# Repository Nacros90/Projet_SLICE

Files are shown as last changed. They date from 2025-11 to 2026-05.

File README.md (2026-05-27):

# Projet SLICE
**Sliding Contact Investigation for Carbon Pantograph Wear Evaluation**

## Description
Ce projet est développé dans le cadre de la 2ème année de Licence de Physique / Sciences de l'Ingénieur. 
Il porte sur l'étude, la simulation et la conception d'un banc expérimental modélisant le contact glissant entre une caténaire et le pantographe d'un train. L'objectif principal est le maintien d'une **vitesse tangentielle constante ($V_t$)** lors du balayage d'un pion sur un disque en rotation, posant un défi cinématique d'asservissement non linéaire ($\omega = \frac{V_t}{r}$).

Ce dépôt regroupe l'intégralité du travail d'ingénierie : la modélisation mathématique initiale, la simulation interactive, le code de contrôle embarqué du banc d'essai et la conception assistée par ordinateur (CAO) des pièces mécaniques.

## Architecture du dépôt

* **Code/** : Contient les simulations cinématiques en Python (modélisation mathématique avec `pygame`) et les programmes C++ Arduino.
* **Documentation/** : Manuels techniques, documentations des composants électroniques (Shield CNC, drivers) et rapports académiques.
* **CAO/** : Fichiers `.stl` (ex: `support_disque.stl`) prêts pour l'impression 3D.

## Matériel et Prérequis

### Composants de la maquette physique
Le banc d'essai s'appuie sur une architecture matérielle spécifique pour s'affranchir des limites de calcul à haute fréquence :
* **Microcontrôleur :** Arduino UNO R4 Minima (Processeur ARM Cortex-M4 32-bits, 48 MHz)
* **Contrôle Moteur :** Shield CNC V3 avec Drivers A4988
* **Actionneurs :** Moteurs pas-à-pas (Axe X pour le disque rotatif, Axe Y pour le balayage linéaire)
* **Configuration mécanique :** Les drivers A4988 doivent être configurés en **Microstepping 1/8** (pontage matériel sur les broches M0 et M1) pour assurer la fluidité du mouvement.

### Outils logiciels
* [Python 3.x](https://www.python.org/) avec la bibliothèque `pygame` (pour la simulation logicielle)
* [Arduino IDE 2.x](https://www.arduino.cc/en/software) (pour la compilation et le téléversement du code embarqué)
* Un logiciel de tranchage (UltiMaker Cura, PrusaSlicer...) pour exploiter les modèles 3D

## Installation et Utilisation

### Étape 1 : Cloner le dépôt
```bash
git clone [https://github.com/nacros90/projet_slice.git](https://github.com/nacros90/projet_slice.git)
cd projet_slice
```

### Étape 2 : Lancer la Simulation (Python)
La simulation permet de visualiser la courbe de vitesse requise par rapport à la position du pion sans nécessiter le déploiement du matériel physique.
```bash
# Installation de la dépendance
pip install pygame

# Lancement du script principal
python Code/Python/slice.py
```

### Étape 3 : Déployer le Contrôle Matériel (Arduino)
Le programme embarqué opère en boucle ouverte et recalcule la vitesse du disque via un échantillonnage spatial régulier.

#### 3.1 Préparation matérielle
1. Ouvrez le fichier `Code/Arduino/Code_maquette_UNO_R4_MINIMA/Code_maquette_UNO_R4_MINIMA.ino` dans l'Arduino IDE.
2. Assurez-vous d'avoir installé le gestionnaire de carte **Arduino UNO R4 Boards**.
3. **Important :** Effectuez le "Zéro Mécanique" en plaçant manuellement le pion sur le bord extérieur du disque ($R_{max} = 7.5$ cm) avant toute mise sous tension.

#### 3.2 Configuration Système et Ports de communication
Avant de téléverser, configurez l'accès aux ports série selon votre système d'exploitation.

**Sous Microsoft Windows :**
* Branchez la carte et ouvrez le **Gestionnaire de périphériques** (`Win + X`).
* Déroulez l'onglet **Ports (COM et LPT)** pour identifier le port attribué (ex: `COM6`).
* *Note :* L'UNO R4 est reconnue nativement. Si vous utilisez une ancienne Nano, le pilote **CH340** peut être requis.
* Dans l'IDE Arduino, sélectionnez ce port COM.

**Sous GNU/Linux (Gestion des droits POSIX) :**
Par défaut, Linux restreint l'accès aux ports série (`/dev/ttyACM0` ou `/dev/ttyUSB0`), ce qui provoquera une erreur `Permission denied` lors du téléversement ou de l'exécution du code Arduino.
* Pour octroyer les droits de manière permanente, ajoutez votre utilisateur au groupe propriétaire du périphérique série :
  * Sous Debian / Ubuntu / Mint : `sudo usermod -aG dialout $USER`
  * Sous Arch Linux / Fedora : `sudo usermod -aG uucp $USER`
* Appliquez la modification sans redémarrer la session en tapant : `newgrp dialout` (ou `newgrp uucp`).
* Dans l'IDE Arduino, sélectionnez le port `/dev/tty...` correspondant.

#### 3.3 Téléversement et Diagnostic
* Cliquez sur **Téléverser** dans l'IDE. Une fois terminé, alimentez le Shield en puissance (8V).

*Matrice de résolution des problèmes courants :*
| Symptôme observé | Cause probable | Action corrective |
| :--- | :--- | :--- |
| **`Permission denied` (Linux)** | Droits restreints sur le port série. | Exécuter la commande `usermod` et `newgrp` (voir 3.2). |
| **Port COM invisible (Windows)** | Absence du pilote USB-Série. | Télécharger et installer le pilote CH340. |
| **`not in sync: resp=0x00`** | Parasitage matériel ou port occupé. | Débrancher le Shield CNC de l'Arduino pour le téléversement ou fermer les logiciels de tranchage 3D. |
| **Décrochage en fin de course** | Limite physique atteinte (FCEM sous 8V). | Vérifier que l'écrêtage à 10 000 pas/s (`constrain`) est bien actif dans le code. |

## Équipe Projet
* Naël CROSNIER
* Théliau FOULER
* Paul MITTLER
* Nysteroye Christ ZEBAZE NGUENA

*Supervisé par l'Université Marie et Louis Pasteur – UFR STGI Belfort*

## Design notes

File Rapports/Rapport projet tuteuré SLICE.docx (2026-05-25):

PROJET TUTEURÉ : SLICE

SLIDING CONTACT INVESTIGATION FOR CARBON PANTOGRAPH WEAR EVALUATION

Naël CROSNIER

Théliau FOULER

Paul MITTLER

Nysteroye Christ ZEBAZE NGUENA

Université Marie et Louis Pasteur – UFR STGI Belfort

Remerciements :

Nous tenons tout d’abord à remercier notre tuteur pédagogique pour ce projet, Philippe BAUCOUR pour son accompagnement tout au long de l’année, ses idées ainsi que ses précieux conseils ayant contribué à l’amélioration de notre maquette.

Nous souhaitons également remercier Cyrille VERNA pour sa disponibilité, son regard avisé sur l’ingénierie de la maquette, ses connaissances physiques et son implication sur l’impression 3D des pièces.

Nous exprimons notre plus grande gratitude envers Oreen OUMER pour le temps qu’il nous a consacré afin de nous présenter son banc d’essai et ses recherches ainsi que pour avoir répondu à nos nombreuses questions sur un sujet complexe.

Les cours de recherche documentaire donnés par Véronique NEYER et Caroline KIMMICH nous ont grandement aidés pour la recherche de sources en lien avec notre sujet, ainsi que dans la construction et la rédaction d’une bibliographie.

Enfin, nous adressons un dernier remerciement à Théo KZYAZIK qui, grâce à sa thèse, nous a permis de compléter notre travail avec des éléments scientifiques pertinents et approfondis.

## TABLE DES MATIERES

Présentation du sujet ............................................................................... p.

I. Etude théorique ................................................................................... p.

II. Amélioration de la maquette ................................................................ p.

2.1. Elements physiques .................................................................... p.

2.2. Arduino ........................................................................................ p.

III. Programmes et gestion des moteurs .................................................. p.

3.1. Arduino ........................................................................................ p.

3.2. Python .................................................... p.

IV. Résultats et Conclusion …………………........…………...................... p.

V. Références bibliographiques ............................................................... p.

VI. Annexes .............................................................................................. p.

6.1. Programme Arduino …………………………................................ p.

6.2. Programme Python ..................................................................... p.

## TABLE DES FIGURES

Figure 1 : Schéma de la liaison Caténaire-Pantographe ....................................... p.

Figure 2 : Photo de la maquette vue du dessus

Figure 3 : Schéma du “zig-zag” de la caténaire entre les poteaux ..................................... p.

Figure 4 : Représentation des grandeurs cinématiques d'un point en mouvement circulaire

Figure 5 : Photo de la maquette montrant le placement et les pièces entraînées par la courroie

## Présentation du sujet :

Les trains font partie des moyens de transport les plus fréquentés en France (environ 11% de la distance totale parcourue par des voyageurs en France en 2023 d’après touteleurope.eu), notamment dû à ses nombreux avantages comme sa sûreté, sa praticité ou bien son faible impact écologique. A l’heure actuelle, de nombreuses questions se posent à propos des trains, que ce que cela soit au niveau sécurité, prix ou encore énergétique. C’est de ce dernier aspect que nous allons plus particulièrement parler.

En effet, aujourd’hui, les trains utilisent un système nommé caténaire-pantographe pour s’alimenter en énergie (ici ce sera de l’énergie électrique).

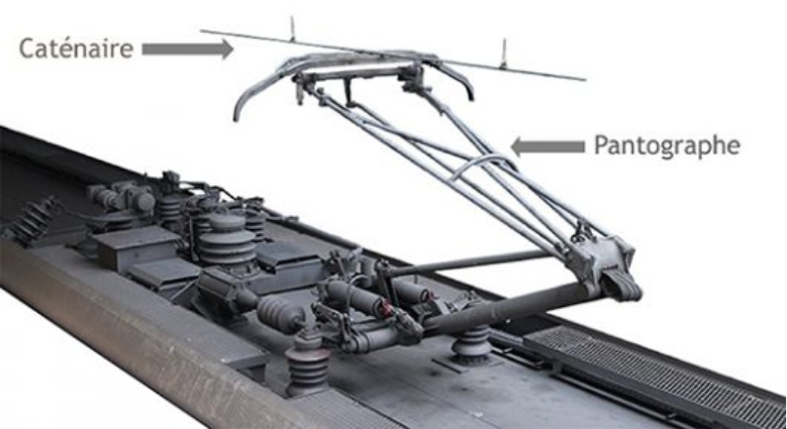
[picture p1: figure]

Figure 1 : Schéma de la liaison Caténaire-Pantographe.

Ce système est constitué d’une caténaire qui est un ensemble de câbles porteurs servant à acheminer l’électricité jusqu’au train. Cette dernière est transmise au train par le pantographe qui est un dispositif articulé formé d’une suite de bras ainsi que d’un archet sur lequel est fixée une bande de frottement. C’est ici que l’électricité va se transmettre au train.

C’est le contact entre caténaire et pantographe qui permet l’alimentation du train. Cette technologie permet un encombrement moindre par rapport aux anciennes technologies comme les locomotives à charbon et à vapeur mais possède un inconvénient de taille : le frottement. En effet, le frottement entre la bande du pantographe avec la caténaire use rapidement la bande sous l’action de la vitesse (plus ou moins grande suivant le type de train) ou encore la présence d’électricité. Cette usure, principalement sur la bande, est l’élément qui a poussé la SNCF en association avec FEMTO ST à travailler sur cette technologie en étudiant comment réduire cette usure et permettre une maintenance moins soutenue.

Pour bien comprendre la situation, nous avons commencé par récupérer la maquette conçue par le groupe affecté à ce même projet l’année dernière sous la tutelle de Philippe Baucour. Cette maquette est constituée d’un disque tournant ainsi que d’un pion (ici représenté par un crayon) dont on contrôlera la rotation ainsi que les déplacements grâce à l'utilisation de moteurs pas à pas et d’un microcontrôleur. Vous trouverez une photo de cette maquette ci-dessous.

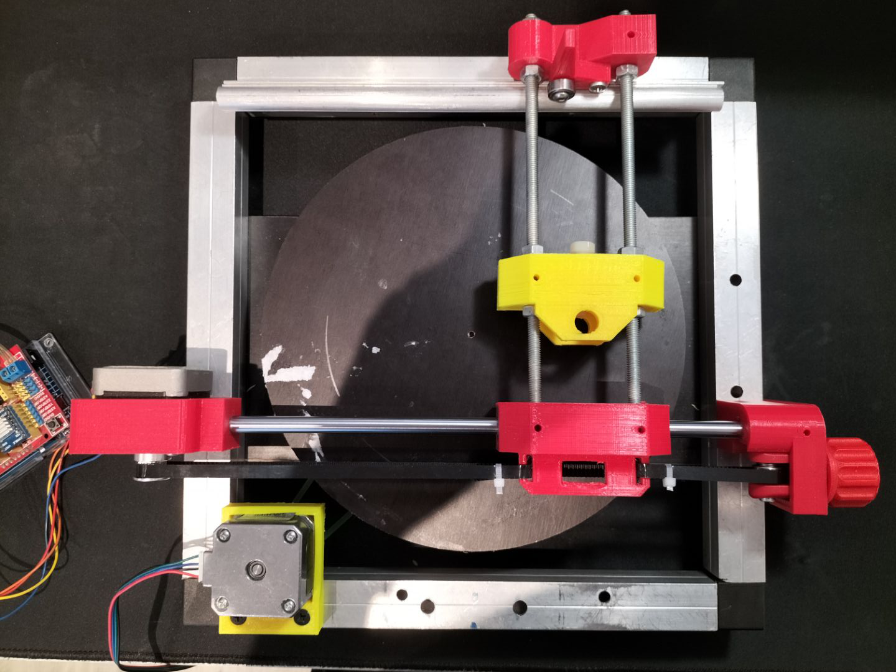
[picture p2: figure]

Figure 2 : Photo de la maquette vue du dessus

Cette maquette est directement inspirée du banc expérimental se trouvant à FEMTO ST

Nous avons justement pu voir ce banc en action et recevoir des explications concrètes sur son fonctionnement lors d’essai effectué par le thésard en charge du projet Oreen OUMER.

Le principe de ce banc est de représenter la vitesse du train (que l’on veut idéalement garder constante) par une vitesse de rotation (celle du disque précédemment cité) pour simuler l’avancement du train. Ce dernier sera quant à lui réduit au point de contact entre le caténaire et le pantographe représenté par un pion en carbone qui va venir se frotter sur le disque lorsque ce dernier tournera. Ce point de contact est déplaçable où l’on veut le long du rayon du disque grâce à des moteurs. Le déplacement le long du rayon sert quant à lui à prendre en compte le mouvement du point de contact entre le caténaire et le pantographe qui glisse le long de la bande de contact.

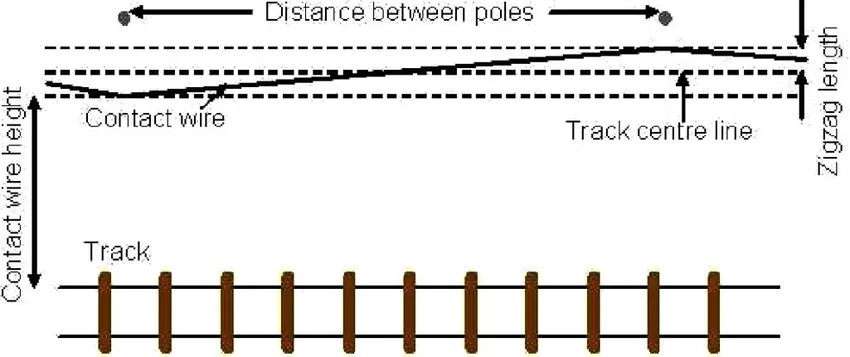
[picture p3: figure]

Figure 3 : Schéma du “zig-zag” de la caténaire entre les poteaux.

Ce mouvement du point est pensé pour réduire l’usure de la bande. En faisant varier la position du point de contact, la bande s’use sur toute sa longueur plutôt que sur un seul point ce qui permet d’augmenter sa durée de vie et de réduire ses risques de sciage.

Une fois cette maquette récupérée, nous avons donc pu commencer l’amélioration de cette dernière que cela soit au niveau de la maquette en elle-même (pièce, dimension, etc) mais surtout sur un autre aspect très important de ce projet qui est le contrôle des moteurs. Pour reproduire au mieux la réalité, la gestion des moteurs est cruciale. Ces moteurs sont contrôlés par un microcontrôleur géré en langage Arduino. Ce dernier nous permet de contrôler les moteurs à notre guise en changeant par exemple leur nombre de pas par seconde, donc leurs vitesses de rotation. La bonne gestion de ces moteurs passe aussi par une étude théorique des mouvements et vitesses des différents éléments de la maquette. Avec ces résultats, nous pouvons, une fois les avoir implantés dans le code Arduino, gérer le plus fidèlement possible à la réalité les moteurs.

Ce projet, étant destiné à être présenté au festival INOUIH, il doit pouvoir être compréhensible par le plus grand nombre. Cela nous amène donc à réfléchir sur comment vulgariser ce projet, les thèmes abordés et le fonctionnement de la maquette. Pour cela, en plus d’explications orales pour expliquer les principes fondamentaux, nous avons aussi cherché un moyen de montrer nos résultats et de les représenter de manière ludique et la plus compréhensible possible. Pour cela, nous utiliserons un programme python relié à un écran nous permettant de montrer l’influence des différents paramètres sur les résultats. Cette simulation se devra d’être le plus fidèle possible à la réalité, c’est pourquoi il faudra aussi y implémenter les différentes équations obtenues après l'étude théorique.

Comme nous avons pu le voir, ce projet possède plusieurs aspects très différents nécessaires au bon déroulement de ce dernier. Nous avons donc sectionné notre travail pour voir dans quel ordre les différentes tâches doivent être réalisées.

## I) Etude théorique :

La première étape de notre travail a été l'étude théorique du fonctionnement mécanique de la maquette. L’objectif étant d’en tirer des équations permettant le bon fonctionnement des programmes de gestion des moteurs. C’est donc une étape très importante. Pour commencer cela, nous partons d’une équation basique très souvent utilisée lors de problème avec des objets en rotation :

V_(tan) =ω⋅r

D’après cette équation, on a :

- V_(tan) (en m/s, qui est la vitesse tangentielle du train donc l’équivalent de sa vitesse réelle, censée être constante idéalement)
- ω (En rad/s) qui est la vitesse de rotation du disque
- r (en mm) étant le rayon du cercle définit par le point de contact entre le disque et le pion

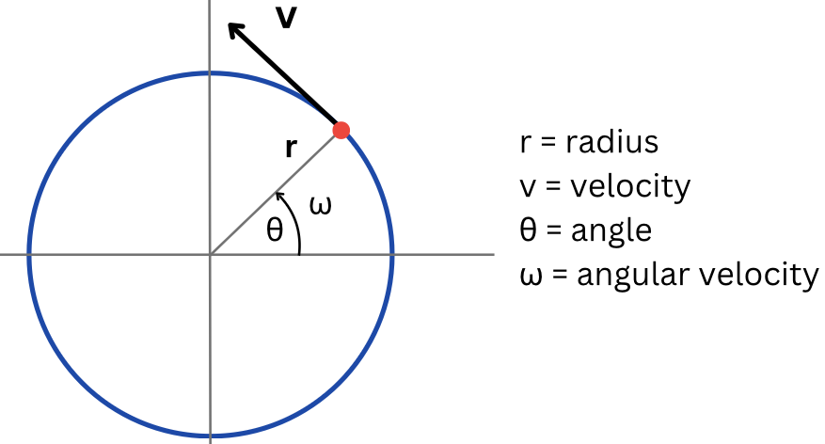
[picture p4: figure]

Figure 4 : Représentation des grandeurs cinématiques d'un point en mouvement circulaire.

Cette équation met donc en relation directe la vitesse tangentielle du train et la vitesse de rotation du disque ce qui nous permet de relier nos deux moteurs.

Notre base étant établie, nous allons maintenant utiliser cette équation pour l’adapter à notre situation. Comme nous le savons, nous avons 2 moteurs sur la maquette, chacun entraînant un élément différent et nécessitant donc une étude différente. Nous nommerons le moteur m_1 (moteur au support jaune) celui qui gère la rotation du disque et le moteur m_2 moteur au support rouge) celui qui gère le déplacement du pion sur le disque.

Pour mieux comprendre ce dont on parle, voici ci-dessous une photo de la maquette avec les différents éléments de cette dernière nommés :

L’objectif ici est de recalculer la vitesse tangentielle en direct pour s’assurer qu’elle reste constante. Les programmes seront chargés de calculer ω en fonction de r car le calcul de r quant à lui dépendra d’une autre relation qui est : d_p = (N⋅R_p)/360

Où N est le nombre de pas effectué par le moteur, Rp est le rayon de la poulie permettant le mouvement du pion le long du rayon du disque ( Rp = 70 mm )

Ce d_p est quant à lui la distance parcourue par le pion le long du rayon du disque. Cette distance sera ajoutée à notre ancien rayon r pour pouvoir le recalculer. Avec cette définition de r, cela nous permet de calculer ω en fonction d’un rayon calculable facilement et d’une vitesse tangentielle constante. Le nombre de pas se détermine expérimentalement pour que la gestion des moteurs soit la plus fluide possible mais tout cela se fera avec les différents programmes informatiques.

Grâce à l’aide de Monsieur Verna nous pu obtenir l’équation suivante :

V_(tan) =ω_1 ⋅r_1 =ω_2 ⋅r_2

Ici ω_1 et ω_2 sont les vitesses de rotation du disque à différents rayons r_1 et r_2 .

Avec ces différentes informations et équations, nous pouvons donc calculer ω en fonction de r qui lui est connu. Cela nous permet que, lorsque l’on fera varier le nombre de pas, ω varie lui aussi pour garder la vitesse tangentielle constante.

## II) Amélioration de la maquette :

### i. Eléments physiques

Une fois la maquette obtenue, nous avons commencé par tenter de là faire fonctionner pour voir s'il y avait d’éventuels problèmes. En effet, une fois la maquette active, des problèmes nous sont apparus comme principalement le fait que le disque n’est pas stable une fois qu’il est en rotation ou encore qu’il tourne de manière saccadée et peu précise. Nous avons donc compris que des améliorations de la maquette s’imposait. C’est ce dont on va parler dans cette partie.

Pour commencer, nous avons cherché à régler le problème de stabilité du plateau. Pour cela, nous avons vu avec M. VERNA et M. BAUCOUR pour modéliser une pièce 3D afin de mieux y fixer le plateau et ainsi éviter tout oscillement. Une première idée était d’entourer le moyeu central et de former une sorte de plateau pour y fixer le disque mais finalement l’essai s’est avéré non concluant. Une seconde idée était une pièce se mettant autour du moyeu mais s’insérant dans le plateau afin d’y mettre une vis et un une vis oreille afin de pouvoir démonter le plateau de façon rapide et simple. Après prise de mesure, modélisation 3D sur Onshape, un premier essai non fonctionnel à cause d'erreurs de mesures, nous avons enfin eu la pièce finale réglant parfaitement le problème.

### ii. Arduino

Le second point d’amélioration est la partie programmation dans le langage Arduino, nous asservissons les moteurs par le biais d’une carte Arduino, dans là qu’elle nous téléversons du code. L’un des objectifs majeurs de cette parties était de programmer un script qui était conforme aux équations mécaniques et cinématiques régissant les mouvements du système plateau-pion.

Initialement confié à une carte Arduino Nano (équipée d'un microcontrôleur ATmega328P), le système souffrait d'un goulot d'étranglement calculatoire sévère. Le maintien de la consigne avec notre rapport de transmission exigeait la génération d'environ 13 300 impulsions par seconde. L'architecture 8-bits de la Nano, cadencée à 16 MHz et dépourvue d'unité de calcul en virgule flottante (FPU), devait émuler les opérations non linéaires complexes de la boucle d'asservissement (divisions, variables de type float, calculs impliquant pi) de manière purement logicielle. Cela entraînait une saturation de l'horloge processeur autour de 4 000 pas/s et un figeage cinématique de la maquette.

La migration vers une carte Arduino UNO R4 Minima a permis de lever cette limite matérielle. Embarquant un processeur ARM Cortex-M4 (32-bits) cadencé à 48 MHz, cette carte intègre une FPU matérielle. Cette architecture permet d'exécuter les opérations en virgule flottante en un nombre très réduit de cycles d'horloge. La boucle logicielle peut désormais générer des fréquences dépassant les 20 000 pas/s sans induire de latence.

L'interface de puissance entre la logique 5V du microcontrôleur et l'alimentation 8V des moteurs pas-à-pas est assurée par un Shield CNC V3 équipé de drivers de type A4988.

Un moteur pas-à-pas standard effectue 200 pas entiers par tour (soit une résolution angulaire de 1,8° par pas). En mode "Full Step", chaque transition de phase génère des transitoires de couple et des résonances mécaniques nuisibles à l'étude tribologique du contact glissant, qui requiert une continuité parfaite.

Afin de lisser la dynamique du mouvement, nous avons modifié la configuration matérielle de la carte de commande pour forcer un fonctionnement en Microstepping.

Tableau : Configuration des états logiques du driver A4988 (Microstepping 1/8)

Paires de broches | État Logique cible | Action matérielle réalisée
M0 (ou MS1) | HIGH (1) | Pont de court-circuit effectué (soudage)
M1 (ou MS2) | HIGH (1) | Pont de court-circuit effectué (soudage)
M2 (ou MS3) | LOW (0) | Contact laissé ouvert

Cette subdivision électronique des courants de phase régule l'intensité sous forme de signaux pseudo-sinusoïdaux, portant la résolution à 1 600 micro-pas par tour. Le mouvement linéaire du pion est ainsi devenu strictement continu, limitant l'excitation des modes propres de la structure.

L'affranchissement des limites logicielles de traitement a mis en exergue une contrainte purement électromagnétique de l'actionneur. Lors du passage du pion dans la zone centrale du disque, la consigne haute fréquence du microcontrôleur provoquait une perte de synchronisme et un décrochage brutal du moteur du plateau (phénomène observé autour de 11 000 pas/s, soit environ 412 Tr/min).

Ce comportement est gouverné par la Force Contre-Électromotrice (FCEM) et l'inductance (L) des enroulements du moteur. La dynamique de montée du courant dans la bobine est régie par l'équation de maille temporelle : (di)/(dt)=(U−E)/L (où E est la FCEM induite par la rotation du rotor).

À haute vitesse angulaire, l'inversion rapide du champ et la forte valeur de la FCEM s'opposent à l'établissement du courant. Sous notre tension d'alimentation contrainte à 8V, le gradient de courant (di)/(dt) est d'autant plus limité : le courant n'a physiquement plus le temps d'atteindre sa valeur nominale avant la commutation de phase suivante. Le couple moteur s'effondre drastiquement, ne parvenant plus à vaincre l'inertie du disque.

Pour pallier cette limitation physique directement imputable à l'alimentation de 8V, un écrêtage par saturation logicielle (limite fixée à 10 000 pas/s) a été implémenté. Ce compromis garantit la stabilité électromagnétique du système en boucle ouverte en bornant le fonctionnement à un domaine cinématique viable.

Un élément important de la maquette est la courroie. Elle sert à transmettre le mouvement créer par le moteur m_1 à l’axe sur lequel le disque se fixe pour pouvoir tourner.

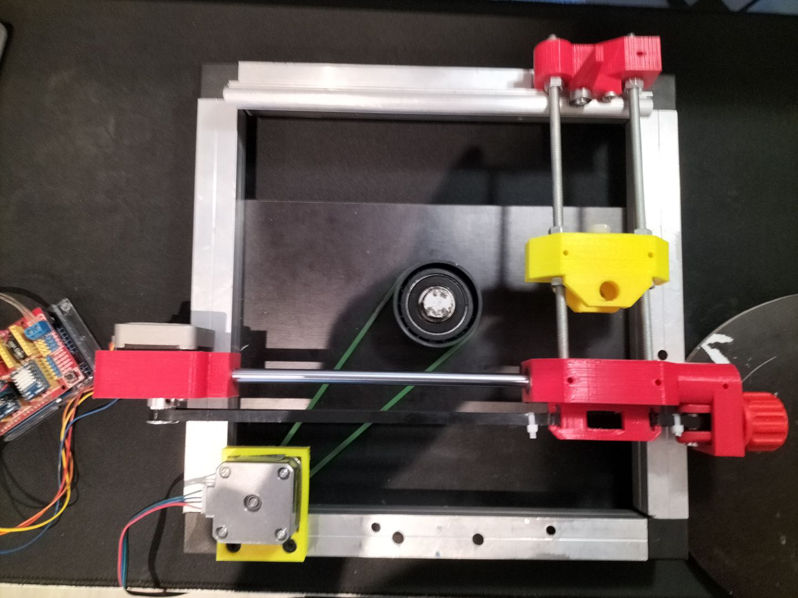
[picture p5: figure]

Figure 5 : Photo de la maquette montrant le placement et les pièces entraînées par la courroie

Cette dernière n’était plus assez tendue donc Monsieur Verna nous en a refait une avec les mêmes dimensions pour nous assurer une plus grande fiabilité et une meilleure précision.

Cette maquette doit permettre de visualiser nos résultats c’est pourquoi nous avons décidé de réfléchir à comment améliorer cette visualisation. Nous avons donc décidé de changer le support servant à représenter le point de contact entre le pion et le disque. Avant, ce pion était modélisé par un crayon que l’on pose sur un support pour que la trajectoire du pion se dessine sur une feuille de papier collée sur le disque quand ce dernier tourne. Cela posait des problèmes de frottements car pour avoir un trait visible, il fallait appuyer le crayon assez fort ce qui n’était pas pratique. De plus, le mouvement saccadé du disque dû aux problèmes précédemment cités, entrainait une trajectoire dessinée peu précise. Pour changer cela, le précédent groupe avait donc penser à utiliser un revêtement de type tableau blanc à coller sur le disque pour que le crayon remplacé par un feutre, puisse plus simplement dessiner la trajectoire du pion en réduisant l’influence des frottements sur les résultats obtenus. Nous avons donc repris cette idée car cela permet aussi de pouvoir effacer la trajectoire dessinée plus facilement qu’avec du papier classique.

D’autres problèmes plus légers sont aussi à régler comme :

- la fixation des moteurs sur leur support, notamment le moteur m_2 qui lorsque la maquette est active, n’était pas très stable. Ce problème détecté par Monsieur Verna lors d’un entretien, a tout de suite été corrigé après avoir fixé ces moteurs aux supports avec des vis.

- la stabilisation générale de la maquette et la diminution des vibrations. Pour cela, nous avons placés des patins anti-dérapants que l’on a collé sous les pieds de la maquette pour réduire les vibrations qu’elle subissait quand elle était active.

Comme nous avons pu le voir, la structure et le fonctionnement général de la maquette n’a pas été modifié. Notre travail se situe surtout la stabilisation des éléments de la maquette comme le disque, la bonne transmission des informations et mouvements avec la gestion des équipements du micro-processeur et de la courroie ou encore améliorer la visibilité de nos résultats.

## III) Programmes et gestion de moteurs :

Pour pouvoir mener à bien nos tests et expériences, il nous faut utiliser des programmes informatiques pour pouvoir gérer les moteurs et afficher nos résultats afin de mieux comprendre ce qu’il se passe. Nous allons donc utiliser deux programmes différents : le premier est un code Arduino qui, à l’aide du microcontrôleur de la carte Arduino, nous permettras de contrôler les moteurs de la manière la plus précise voulue afin d’obtenir les meilleurs résultats possibles. Le deuxième est un programme Python qui sert quant à lui à afficher nos résultats de manière visuelle pour simplifier la compréhension du sujet à un public non initié.

Nous allons commencer par aborder le programme Arduino car il est nécessaire au bon fonctionnement de la maquette.

### iii. Arduino

Contrairement au code Python dont l'objectif principal est la simulation et la visualisation des données, le programme Arduino constitue le cœur opérationnel de notre maquette. Son rôle est de traduire les résultats de notre étude cinématique théorique en signaux électriques concrets afin de piloter les moteurs pas-à-pas en temps réel. Pour garantir une gestion précise des signaux, ce programme s'appuie sur la bibliothèque externe AccelStepper et a été rigoureusement structuré en trois blocs distincts.

1. Initialisation et Variables globales

Ce premier bloc prépare l'environnement matériel et logiciel de la carte (Arduino UNO R4 Minima). Il définit d'abord le câblage du microcontrôleur vers le Shield CNC, puis modélise les caractéristiques mécaniques de la maquette, notamment l'activation du Microstepping (réglé sur 1/8 de pas pour réduire les vibrations) et l'intégration de notre rapport de transmission (multiplicateur_mecanique). C'est également ici que sont déclarées les constantes physiques fondamentales au cœur de l'étude, à savoir la vitesse tangentielle cible (25 cm/s) et les limites spatiales du disque. Enfin, pour protéger l'intégrité du matériel, des garde-fous logiciels (écrêtage de la vitesse maximale) sont fixés afin d'éviter le décrochage électromagnétique du moteur face aux très hautes fréquences d'impulsion.

2. Boucle principale

Ce bloc, s'exécutant en continu à haute fréquence, constitue le cœur de notre asservissement. Il orchestre deux processus cinématiques simultanés. D'une part, il gère le balayage linéaire du pion en contrôlant ses allers-retours autonomes entre le bord et le centre du disque. D'autre part, il assure la régulation dynamique de la vitesse du plateau. Afin d'optimiser la puissance de calcul du processeur et d'éviter les saccades, le recalcul de la vitesse n'est pas effectué à chaque micro-pas, mais selon un échantillonnage spatial défini (SEUIL_PAS_Y). À chaque palier, le programme déduit le rayon actuel et applique l'équation cinématique de base ( ω=(V_(tan))/r ) pour ajuster instantanément la vitesse de rotation du disque. L'écrêtage de sécurité (constrain) garantit que si la vitesse angulaire requise tend vers l'infini près du centre du disque, elle est automatiquement bridée au plafond toléré par le moteur.

3. Fonctions mathématiques

Le dernier bloc regroupe les outils de conversion essentiels au système. L'architecture de la maquette fonctionnant en boucle ouverte (sans capteur de position absolu), l'Arduino est initialement aveugle à la position physique du pion. Ces fonctions permettent de lier les variables informatiques à la réalité mécanique. Elles convertissent les grandeurs mécaniques (RPM) en signaux électriques temporels (pas par seconde), et surtout, elles convertissent le comptage logiciel des pas du moteur en une véritable coordonnée spatiale géométrique (le rayon actuel en centimètres), donnée indispensable à la résolution de l'équation dans la boucle principale.

### iv. Python

Nous allons maintenant nous penchés sur le code Python. Ce dernier n’est pas nécessaire au fonctionnement de la maquette car il ne commande pas les moteurs. Son but est de visualiser les résultats de manière ludique et compréhensible. Pour cela, nous avons utilisé une bibliothèque appelée Pygame. C’est un ensemble de module nous permettant de créer des simulations comme celle utilisée ou bien même des jeux comme nous avons pu le faire lors d’un cours du premier semestre. Cette bibliothèque est très utile car elle nous permet de structurer le code de la simulation comme on le souhaite.

En effet, un code bien construit permet une exploration et utilisation plus simple de celui-ci. C’est pourquoi nous avons arrangé notre code en plusieurs blocs ayant tous une fonction propre.

Le premier bloc sert à initialiser donc définir toutes les variables dont on a besoin ainsi qu'importer toutes les bibliothèques nécessaires dont Pygame. Les autres bibliothèques servent quant à elles à nous permettre d’utiliser des fonctions mathématiques ou encore de faciliter la gestion des objets en mouvements. Ce bloc est la base du code, il est donc important de définir toutes les variables dont nous avons besoin pour plus tard. Ces variables peuvent être les différentes grandeurs physiques comme des vitesses ou des rayons ou bien encore des éléments de la simulation comme la taille de l’écran ou bien les couleurs de ce dernier.

Le deuxième bloc sert à définir les fonctions. Ces fonctions transforment et utilisent les variables définies avant pour effectuer des calculs comme ceux de la vitesse tangentielle, tracer des formes comme le pion que l’on va faire bouger. Ces fonctions forment la structure de la simulation. Ce sont elles qui vont définir son apparence, comment elle va traiter les données et à quoi elle va servir. Elles sont en quelques sortes le squelette de la simulation. Il est donc logique de les séparer de l’initialisation des variables (qui est naturellement avant les fonctions) et de la suite du code qui sert encore à une autre chose.

Le dernier bloc est celui de la boucle principale. Cette boucle est le cœur du programme. Elle commence dès que l’utilisateur lance le programme et s’arrête lorsque l’utilisateur le ferme. Elle sert à actualiser les données et à les afficher en temps réel. Elle gère la gestion des entrées donc les touches utilisées par l’utilisateur, met à jour les résultats des calculs et rafraichît l’affichage de la simulation à chaque fois que la boucle est effectuée. Cette boucle se servant des fonctions et des variables, il est logique de la placer à la toute fin de ce dernier pour lui permettre d’utiliser tout ce dont elle a besoin.

L’objectif de séparer le code en plusieurs blocs est double : trouver plus simplement les lignes et les parties que l’on veut et permettre une meilleure compréhension de la logique d’un code et du fonctionnement de la simulation.

## IV) Résultats et Conclusion :

En conclusion, les développements matériels et logiciels apportés à la maquette initiale ont permis de répondre pleinement aux exigences de ce banc d'essai cinématique. Comme l'a validé notre simulation Python en amont, l'implémentation de notre modèle mathématique garantit le maintien d'une vitesse tangentielle constante en dépit de la variation continue du rayon. Le défi majeur des saccades mécaniques a été résolu par l'exploitation du microstepping (1/8 de pas), apportant ainsi la fluidité de glissement indispensable à une modélisation de l'usure du pantographe.

Par ailleurs, l'optimisation de ce système ne s'est pas limitée à l'aspect algorithmique. La conception et l'impression 3D de nouvelles pièces de maintien, couplées à l'ajout de patins amortisseurs, ont considérablement réduit les résonances et stabilisé le disque en rotation.

D'un point de vue gestion de projet, ce travail a mis en lumière l'importance d'une planification rigoureuse. L'organisation initiale s'est révélée sous-optimale face à la complexité du travail prévue, entraînant des retards notables sur notre calendrier prévisionnel. Toutefois, cette confrontation à la réalité expérimentale nous a poussés à réévaluer nos méthodes de travail collaboratif. Cette capacité d'adaptation nous a permis de surmonter ces obstacles et d'atteindre, in fine, l'ensemble des objectifs techniques fixés.

Ce projet nous a ainsi permis de consolider une approche d'ingénierie multidisciplinaire, alliant la modélisation théorique, la programmation embarquée et la conception mécanique. La maquette est aujourd'hui fonctionnelle, stabilisée et fidèle à la réalité physique.

## V) Bibliographie :

[https://ecampusontario.pressbooks.pub/] (figure 3)

https://www.researchgate.net/figure/Layout-of-an-overhead-electrified-railway-showing-the-zigzag-of-the-contact-wire-adapted_fig3_224219101

https://actgv.fr/wp-content/uploads/2014/04/cat%C3%A9naire-et-fils-de-contact.pdf

- Enrici P, Martiré T, Coillot C, Huselstein JJ. Maquette analogique pour l’étude de boucle de régulation. Application à la régulation d’un Moteur à Courant Continu. Journal sur l'enseignement des sciences et technologies de l'information et des systèmes. 2023;22:1015.
- Janssoone D. Manuel d’exploitation ferroviaire: formation des exploitations du ferroviaire, IUT, CNAM, écoles d’ingénieurs. Malakoff: Dunod; 2024.
- Bausseron T. Etude de l'échauffement de la caténaire lors du captage à l'arrêt: développement d'un outil informatique [Thèse de doctorat]. Besançon: Université de Franche-Comté; 2014.
- Jonckheere B. Caractérisation multi-physique d'une interface multi-contacts à l'arrêt et en mouvement: cas du captage de courant via l'interface caténaire-pantographe [Thèse de doctorat en ligne]. Amiens: Université de Picardie Jules Verne; 2021 [cité 13 novembre 2025]. Disponible sur: https://theses.hal.science/tel-03828928
- Cincou A, Fortin C. Guide de modélisation 3D: document de référence. Montréal: Presses Internationales Polytechnique; 2019.
- Kziazyk T. Etude expérimentale de l'usure et de l'échauffement d'un contact électrique glissant: application caténaire-pantographe [Thèse de doctorat en ligne]. Besançon: Université de Bourgogne Franche-Comté; 2023 [cité 06 novembre 2025]. Disponible sur: https://ariane.umlp.fr/discovery/fulldisplay?docid=alma991006709719506657&contex t=L&vid=33UFC_INST:33UFC_INST&lang=fr&search_scope=MyInst_and_CI&adapt or=Local%20Search%20Engine&tab=Everything&query=any,contains,Etude%20exp %C3%A9rimentale%20de%20l%27usure%20et%20de%20l%27%C3%A9chauffeme nt%20d%27un%20contact%20%C3%A9lectrique%20glissant%20:%20application%2 0cat%C3%A9naire-pantographe&offset=0
- Delcey N. Modélisation électro-thermique d’un pantographe pour un train en mouvement [Thèse de doctorat en ligne]. Besançon: Université de Bourgogne Franche-comté; 2018 [cité 05/12/2025] Disponible sur : https://ariane.umlp.fr/discovery/fulldisplay?docid=alma991006234119706657&contex t=L&vid=33UFC_INST:33UFC_INST&lang=fr&search_scope=MyInst_and_CI&adapt or=Local%20Search%20Engine&tab=Everything&query=any,contains,contact%20ele ctrique%20pour%20les%20trains&offset=0
- Sreejyothi KR, Chenchireddy K, Srujana A, Nagaraju D, Ramcharan G, Raghu D. Arduino based stepper motor speed regulation for robotics applications. International Journal of Applied Power Engineering (IJAPE) [En ligne]. 2024 [cité 05 décembre 2025];13(3):695-702. Disponible sur: http://doi.org/10.11591/ijape.v13.i3.pp695-702

## VI) Annexe

### v. Code Arduino :

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
//Maquette de démonstration pour le projet SLICE

//Objectif : Contrôler un moteur linéaire (pion) et un moteur rotatif (disque) en synchronisation

//avec une vitesse tangentielle constante pour le pion.

//

//Matériel :

//- Arduino UNO R4 MINIMA

//- Shield CNC pour contrôler les moteurs pas à pas

//- Moteur linéaire (pion) avec driver compatible

//- Moteur rotatif (disque) avec driver compatible

//

//Fonctionnement :

//- Le moteur Y (pion) effectue un mouvement linéaire aller-retour entre deux positions définies.

//- Le moteur X (disque) ajuste sa vitesse de rotation en fonction de la position du pion pour maintenir une vitesse tangentielle constante.

//

//Note : Ce code est conçu pour être utilisé en mode FULL STEP pour une meilleure précision et un contrôle plus fin des moteurs. Assurez-vous que les drivers de vos moteurs sont configurés pour le microstepping approprié (1/8 dans ce cas) pour correspondre aux constantes définies dans le code.

// 1. --- Initialisation et Variables globales ---

#include <AccelStepper.h>

// --- BROCHES DU SHIELD CNC ---

#define EN 8 // Broche d'activation du shield

#define STEP_Y 3 // Broche STEP du moteur Y (pion)

#define DIR_Y 6 // Broche DIR du moteur Y

#define STEP_X 2 // Broche STEP du moteur X (plateau/disque)

#define DIR_X 5 // Broche DIR du moteur X

// --- RÉSOLUTION MÉCANIQUE (FULL STEP) ---

const int MICROSTEPPING = 8; // Microstepping du driver (1/8 de pas)

const float multiplicateur_mecanique = 2.83;

const int stepsPerRevolutionX = (200 * MICROSTEPPING) * multiplicateur_mecanique; // Pas par tour du moteur X

const int stepsPerRevolutionY = 200 * MICROSTEPPING; // Pas par tour du moteur Y

// --- CONSTANTES PHYSIQUES ---

const float VITESSE_TANGENTIELLE_CIBLE = 25.0; // Vitesse tangentielle du pion en cm/s

const float vitesseY_RPM = 0.5; // Vitesse de rotation du moteur Y en RPM

const int pasParCycle = 290 * MICROSTEPPING; // Nombre de pas pour un cycle aller-retour du pion

const float RAYON_MAX = 7.5; // Rayon maximal du disque en cm

const float RAYON_MIN = 1.35; // Rayon minimal du disque en cm

// --- CONSTANTES DE RÉGLAGE LOGICIEL ---

const long SEUIL_PAS_Y = 16; // Seuil de variation en pas pour recalculer la vitesse X

const float VITESSE_X_MIN = 10.0; // Vitesse minimale autorisée pour le plateau X

const float VITESSE_X_MAX = 10000.0; // Vitesse maximale autorisée pour le plateau X

const float SEUIL_DIFF_VITESSE_X = 2.0; // Seuil de variation de vitesse pour appliquer un nouveau réglage

AccelStepper moteurY(AccelStepper::DRIVER, STEP_Y, DIR_Y);

AccelStepper moteurX(AccelStepper::DRIVER, STEP_X, DIR_X);

long positionDepart = 0; // Position au début du cycle Y

long positionCible = pasParCycle; // Position cible initiale pour le mouvement Y

long dernierPasY = 0; // Position Y mémorisée pour limiter les recalculs

float vitesseX_actuelle = 0.0; // Vitesse courante appliquée au moteur X

void setup() {

Serial.begin(115200);

// --- ACTIVATION DU SHIELD ---

pinMode(EN, OUTPUT);

digitalWrite(EN, LOW);

// Initialisation Moteur Y (Pion)

moteurY.setMaxSpeed(convertRPMToStepsPerSec(vitesseY_RPM, stepsPerRevolutionY));

moteurY.setSpeed(convertRPMToStepsPerSec(vitesseY_RPM, stepsPerRevolutionY));

// Initialisation Moteur X (Disque)

moteurX.setMaxSpeed(VITESSE_X_MAX);

moteurX.setSpeed(100);

Serial.println("Initialisation SLICE (Mode FULL STEP) OK.");

}

// 2. --- BOUCLE PRINCIPALE ---

void loop() {

moteurY.runSpeed();

moteurX.runSpeed();

// --- GESTION DU MOTEUR Y (ALLER-RETOUR DU PION) ---

// Quand le pion atteint la cible, on inverse sa direction

if ((moteurY.currentPosition() >= positionCible && moteurY.speed() > 0) ||

(moteurY.currentPosition() <= positionCible && moteurY.speed() < 0)) {

moteurY.setSpeed(-moteurY.speed());

positionDepart = moteurY.currentPosition();

// Nouvelle cible dépendante du sens actuel du mouvement

positionCible = positionDepart + (pasParCycle * (moteurY.speed() > 0 ? 1 : -1));

Serial.print("Inversion Y. Cible : ");

Serial.println(positionCible);

}

// --- ASSERVISSEMENT DU MOTEUR X (VITESSE DU DISQUE) ---

long positionY = abs(moteurY.currentPosition());

if (abs(positionY - dernierPasY) >= SEUIL_PAS_Y) {

float rayon = mapPasToRayonSymetrique(positionY);

// Calcul de la vitesse angulaire nécessaire pour garder la vitesse tangentielle cible

float vitesseX = (VITESSE_TANGENTIELLE_CIBLE * stepsPerRevolutionX) / (2.0 * PI * rayon);

vitesseX = constrain(vitesseX, VITESSE_X_MIN, VITESSE_X_MAX);

if (abs(vitesseX - vitesseX_actuelle) > SEUIL_DIFF_VITESSE_X) {

moteurX.setSpeed(vitesseX);

vitesseX_actuelle = vitesseX;

Serial.print("Rayon(cm):");

Serial.print(rayon);

Serial.print("\tVitesse_Plateau(pas/s):");

Serial.print(vitesseX);

Serial.print("\tPosition_Pion(pas):");

Serial.println(positionY);

}

dernierPasY = positionY;

}

}

// --- FONCTIONS MATHÉMATIQUES ---

float convertRPMToStepsPerSec(float rpm, int stepsPerRev) {

return (rpm * stepsPerRev) / 60.0;

}

float mapPasToRayonSymetrique(long pas) {

long cycle = pas % (2 * pasParCycle);

float phase = (cycle < pasParCycle) ? (float)(pasParCycle - cycle) / pasParCycle

: (float)(cycle - pasParCycle) / pasParCycle;

return RAYON_MIN + (RAYON_MAX - RAYON_MIN) * phase;

}

### vi. Code Python:

import sys # Permet de quitter proprement le programme

import math # Permet d’utiliser pi, cos, sin, etc.

import pygame # Bibliothèque utilisée pour l’affichage graphique

pygame.init() # Initialisation de Pygame

# =========================================================

# FENÊTRE

# =========================================================

WIDTH, HEIGHT = 1400, 900 # Dimensions de la fenêtre

FPS = 60 # Nombre d’images par seconde

screen = pygame.display.set_mode((WIDTH, HEIGHT)) # Création de la fenêtre

pygame.display.set_caption("SLICE - Banc expérimental avec courbes") # Titre

clock = pygame.time.Clock() # Horloge pour contrôler la vitesse

# =========================================================

# COULEURS

# =========================================================

DARK_BG = (6, 8, 18) # Fond sombre

PANEL_BG = (235, 240, 250) # Fond clair des panneaux

WHITE = (245, 245, 245) # Blanc

BLACK = (0, 0, 0) # Noir

GRAY = (80, 90, 110) # Gris

YELLOW = (255, 220, 80) # Jaune

COPPER = (190, 115, 45) # Couleur cuivre du disque

COPPER_LIGHT = (230, 150, 70) # Cuivre clair

COPPER_DARK = (90, 50, 20) # Cuivre foncé

CARBON = (45, 45, 45) # Couleur du pion carbone

BLUE = (40, 120, 255) # Bleu

RED = (255, 80, 80) # Rouge

GREEN = (80, 200, 120) # Vert

# =========================================================

# POLICES

# =========================================================

FONT = pygame.font.SysFont("consolas", 24) # Police normale

FONT_SMALL = pygame.font.SysFont("consolas", 18) # Petite police

FONT_BIG = pygame.font.SysFont("arialblack", 36) # Grande police

# =========================================================

# PARAMÈTRES PHYSIQUES DU CODE ARDUINO

# =========================================================

RAYON_MIN_CM = 1.35 # Rayon minimal réel en cm

RAYON_MAX_CM = 7.5 # Rayon maximal réel en cm

V0_CM_S = 25.0 # Vitesse tangentielle cible en cm/s

# =========================================================

# GÉOMÉTRIE VISUELLE

# =========================================================

CENTER = (400, HEIGHT // 2 + 40) # Centre du disque décalé vers la gauche

R_DISK_PX = 300 # Rayon graphique du disque en pixels

PX_PAR_CM = R_DISK_PX / RAYON_MAX_CM # Conversion : nombre de pixels pour 1 cm

r_min_px = RAYON_MIN_CM * PX_PAR_CM # Rayon minimal converti en pixels

r_max_px = RAYON_MAX_CM * PX_PAR_CM # Rayon maximal converti en pixels

# =========================================================

# VARIABLES DE SIMULATION

# =========================================================

Nbp = 200 # Nombre de points utilisé pour régler le déplacement

Rp = 70 # Paramètre de déplacement du pion

r_px = float(r_min_px) # Position initiale du pion en pixels

r_dir = 1.0 # Sens du déplacement du pion

theta = 0.0 # Angle de rotation du disque

paused = False # Variable de pause

# =========================================================

# SURFACES POUR TRACE ET HEATMAP

# =========================================================

trace_surf = pygame.Surface((WIDTH, HEIGHT), pygame.SRCALPHA) # Surface de trace blanche

heat_surf = pygame.Surface((WIDTH, HEIGHT), pygame.SRCALPHA) # Surface de heatmap rouge

heat_surf.fill((0, 0, 0, 0)) # Fond transparent

visit = {} # Dictionnaire qui compte les passages du pion

# =========================================================

# DONNÉES POUR LES COURBES

# =========================================================

rayon_data = [] # Liste des rayons en cm

omega_data = [] # Liste des vitesses angulaires

vt_data = [] # Liste des vitesses tangentielles

MAX_POINTS = 250 # Nombre maximal de points affichés sur le graphe

# =========================================================

# CONVERSION PIXELS -> CM

# =========================================================

def px_to_cm(val_px):

return val_px / PX_PAR_CM # Convertit une distance en pixels vers cm

# =========================================================

# POSITION DU PION

# =========================================================

def pion_world_pos(r_val):

cx, cy = CENTER # Récupération du centre du disque

return cx + r_val, cy # Le pion se déplace horizontalement

# =========================================================

# FOND DE L’ÉCRAN

# =========================================================

def draw_background():

screen.fill(DARK_BG) # Efface l’écran avec un fond sombre

for x in range(0, WIDTH, 50): # Lignes verticales de la grille

pygame.draw.line(screen, (18, 22, 38), (x, 0), (x, HEIGHT), 1)

for y in range(0, HEIGHT, 50): # Lignes horizontales de la grille

pygame.draw.line(screen, (18, 22, 38), (0, y), (WIDTH, y), 1)

pygame.draw.circle(screen, (20, 30, 55), CENTER, R_DISK_PX + 45, 3) # Cercle décoratif

# =========================================================

# DESSIN DU DISQUE

# =========================================================

def draw_disk(angle_rad):

cx, cy = CENTER # Centre du disque

pygame.draw.circle(screen, (0, 0, 0), (cx + 10, cy + 12), R_DISK_PX) # Ombre

pygame.draw.circle(screen, COPPER, (cx, cy), R_DISK_PX) # Disque

for i in range(0, R_DISK_PX, 20): # Cercles internes pour effet métallique

color = (

max(80, COPPER[0] - i // 3),

max(45, COPPER[1] - i // 4),

max(20, COPPER[2] - i // 5)

)

pygame.draw.circle(screen, color, (cx, cy), R_DISK_PX - i, 2)

pygame.draw.circle(screen, COPPER_DARK, (cx, cy), R_DISK_PX, 8) # Bord foncé

pygame.draw.circle(screen, COPPER_LIGHT, (cx, cy), R_DISK_PX - 10, 2) # Bord clair

pygame.draw.circle(screen, (30, 30, 30), (cx, cy), 18) # Axe central

pygame.draw.circle(screen, WHITE, (cx, cy), 18, 2) # Contour de l’axe

L = R_DISK_PX - 20 # Longueur du rayon tournant

x2 = cx + L * math.cos(angle_rad) # Coordonnée x du bout du rayon

y2 = cy + L * math.sin(angle_rad) # Coordonnée y du bout du rayon

pygame.draw.line(screen, WHITE, (cx, cy), (int(x2), int(y2)), 4) # Rayon tournant

pygame.draw.circle(screen, WHITE, (int(x2), int(y2)), 7) # Point au bout

# =========================================================

# DESSIN DU PION

# =========================================================

def draw_pion(r_val):

cx, cy = CENTER # Centre du disque

xw, yw = pion_world_pos(r_val) # Position du pion

pygame.draw.line(screen, (220, 220, 220), (cx, cy), (int(xw), int(yw)), 4) # Bras gris

pygame.draw.line(screen, BLUE, (cx, cy + 6), (int(xw), int(yw + 6)), 2) # Bras bleu

pygame.draw.circle(screen, (0, 0, 0), (int(xw + 4), int(yw + 5)), 15) # Ombre du pion

pygame.draw.circle(screen, CARBON, (int(xw), int(yw)), 16) # Pion carbone

pygame.draw.circle(screen, (100, 100, 100), (int(xw), int(yw)), 16, 3) # Contour

pygame.draw.circle(screen, WHITE, (int(xw - 5), int(yw - 5)), 4) # Reflet

# =========================================================

# TRACE ET HEATMAP

# =========================================================

def update_trace(r_val):

xw, yw = pion_world_pos(r_val) # Position du pion

pygame.draw.circle(trace_surf, (255, 255, 255, 45), (int(xw), int(yw)), 3) # Trace blanche

gx, gy = int(xw // 5), int(yw // 5) # Réduction de résolution pour la heatmap

key = (gx, gy) # Case visitée

visit[key] = visit.get(key, 0) + 1 # Incrémente le nombre de passages

alpha = min(210, 15 + visit[key] * 4) # Intensité rouge selon le nombre de passages

pygame.draw.rect(

heat_surf,

(255, 60, 60, alpha),

pygame.Rect(gx * 5, gy * 5, 5, 5)

)

# =========================================================

# PANNEAU D’INFORMATIONS

# =========================================================

def draw_hud(r_val, omega_val, nbp_val):

rayon_cm = px_to_cm(r_val) # Conversion du rayon en cm

v_tan_cm_s = omega_val * rayon_cm # Calcul de la vitesse tangentielle

panel_x = 860 # Position x du panneau décalée

panel_y = 30 # Position y du panneau

panel_w = 500 # Largeur du panneau augmentée

panel_h = 390 # Hauteur du panneau

panel_rect = pygame.Rect(panel_x, panel_y, panel_w, panel_h)

pygame.draw.rect(screen, PANEL_BG, panel_rect, border_radius=18) # Fond du panneau

pygame.draw.rect(screen, (20, 40, 80), panel_rect, 4, border_radius=18) # Bordure

title = FONT_BIG.render("BANC SLICE", True, (10, 25, 60)) # Titre

screen.blit(title, (panel_x + 55, panel_y + 40)) # Affichage du titre

subtitle = FONT_SMALL.render("Grandeurs en cm", True, GRAY) # Sous-titre

screen.blit(subtitle, (panel_x + 55, panel_y + 100)) # Affichage sous-titre

lines = [

f"Nbp : {nbp_val}",

f"Rayon : {rayon_cm:.2f} cm",

f"Vitesse angulaire : {omega_val:.3f} rad/s",

f"Vt reelle : {v_tan_cm_s:.2f} cm/s",

f"V0 cible : {V0_CM_S:.1f} cm/s"

]

y = panel_y + 145 # Position verticale du premier texte

for s in lines: # Affichage ligne par ligne

surf = FONT.render(s, True, BLACK)

screen.blit(surf, (panel_x + 55, y))

y += 40

pygame.draw.line(screen, (20, 40, 80), (panel_x + 40, panel_y + 330),

(panel_x + panel_w - 40, panel_y + 330), 2) # Séparation

commandes = [

"ESPACE : Pause",

"UP/DOWN: Modifier Nbp",

"ESC : Quitter"

]

y = panel_y + 345 # Position des commandes

for cmd in commandes: # Affichage des commandes

surf = FONT_SMALL.render(cmd, True, (120, 40, 20))

screen.blit(surf, (panel_x + 55, y))

y += 22

# =========================================================

# BARRE DE VITESSE ANGULAIRE

# =========================================================

def draw_speed_bar(omega_val):

bar_x = 860 # Position x de la barre décalée

bar_y = 455 # Position y de la barre

bar_w = 500 # Largeur de la barre augmentée

bar_h = 38 # Hauteur

value = min(1.0, omega_val / 10) # Normalisation pour la largeur de la barre

txt = FONT_SMALL.render("Niveau de vitesse angulaire", True, WHITE)

screen.blit(txt, (bar_x, bar_y - 32))

pygame.draw.rect(screen, PANEL_BG, (bar_x, bar_y, bar_w, bar_h), border_radius=15)

pygame.draw.rect(screen, (20, 40, 80), (bar_x, bar_y, bar_w, bar_h), 3, border_radius=15)

pygame.draw.rect(

screen,

BLUE,

(bar_x + 4, bar_y + 4, int((bar_w - 8) * value), bar_h - 8),

border_radius=12

)

# =========================================================

# GRAPHIQUE DES COURBES

# =========================================================

def draw_graph():

graph_x = 860 # Position x du graphe décalée

graph_y = 535 # Position y du graphe

graph_w = 500 # Largeur du graphe augmentée

graph_h = 320 # Hauteur du graphe

pygame.draw.rect(screen, PANEL_BG, (graph_x, graph_y, graph_w, graph_h), border_radius=15)

pygame.draw.rect(screen, (20, 40, 80), (graph_x, graph_y, graph_w, graph_h), 3, border_radius=15)

title = FONT_SMALL.render("Courbes en temps reel", True, BLACK)

screen.blit(title, (graph_x + 18, graph_y + 12))

legend_y = graph_y + 42 # Position de la légende

pygame.draw.circle(screen, RED, (graph_x + 22, legend_y), 6)

screen.blit(FONT_SMALL.render("Rayon", True, BLACK), (graph_x + 35, legend_y - 9))

pygame.draw.circle(screen, BLUE, (graph_x + 135, legend_y), 6)

screen.blit(FONT_SMALL.render("Vitesse angulaire", True, BLACK), (graph_x + 148, legend_y - 9))

pygame.draw.circle(screen, GREEN, (graph_x + 355, legend_y), 6)

screen.blit(FONT_SMALL.render("Vt", True, BLACK), (graph_x + 368, legend_y - 9))

plot_x = graph_x + 60 # Début x de la zone de tracé décalé à l’intérieur

plot_y = graph_y + 75 # Début y de la zone de tracé

plot_w = graph_w - 100 # Largeur zone de tracé ajustée

plot_h = graph_h - 110 # Hauteur zone de tracé

pygame.draw.line(screen, BLACK, (plot_x, plot_y + plot_h),

(plot_x + plot_w, plot_y + plot_h), 2) # Axe horizontal

pygame.draw.line(screen, BLACK, (plot_x, plot_y),

(plot_x, plot_y + plot_h), 2) # Axe vertical

for i in range(1, 5): # Grille horizontale

y = plot_y + int(i * plot_h / 5)

pygame.draw.line(screen, (200, 200, 200), (plot_x, y), (plot_x + plot_w, y), 1)

def scale_points(data, min_val, max_val):

points = [] # Liste des points convertis

if len(data) < 2: # Il faut au moins deux points

return points

for i, val in enumerate(data):

x = plot_x + int(i * plot_w / (MAX_POINTS - 1))

y = plot_y + plot_h - int((val - min_val) * plot_h / (max_val - min_val))

y = max(plot_y, min(plot_y + plot_h, y))

points.append((x, y))

return points

if len(rayon_data) > 2: # Tracé seulement si assez de points

points_rayon = scale_points(rayon_data, RAYON_MIN_CM, RAYON_MAX_CM)

points_omega = scale_points(omega_data, 0, 20)

points_vt = scale_points(vt_data, 0, V0_CM_S * 1.2)

pygame.draw.lines(screen, RED, False, points_rayon, 2)

pygame.draw.lines(screen, BLUE, False, points_omega, 2)

pygame.draw.lines(screen, GREEN, False, points_vt, 2)

# =========================================================

# BOUCLE PRINCIPALE

# =========================================================

while True:

dt = clock.tick(FPS) / 1000.0 # Temps écoulé entre deux images

for event in pygame.event.get(): # Lecture des événements

if event.type == pygame.QUIT:

pygame.quit()

sys.exit()

if event.type == pygame.KEYDOWN:

if event.key == pygame.K_ESCAPE:

pygame.quit()

sys.exit()

if event.key == pygame.K_SPACE:

paused = not paused

keys = pygame.key.get_pressed() # Lecture continue du clavier

if keys[pygame.K_UP]:

Nbp += 1 # Augmente Nbp

if keys[pygame.K_DOWN]:

Nbp = max(1, Nbp - 1) # Diminue Nbp sans descendre sous 1

dx = (Nbp * Rp) / 360 # Vitesse radiale du pion

if not paused:

r_px += r_dir * dx * dt # Déplacement du pion

if r_px >= r_max_px:

r_px = float(r_max_px)

r_dir = -1.0

elif r_px <= r_min_px:

r_px = float(r_min_px)

r_dir = 1.0

rayon_cm = px_to_cm(r_px) # Rayon actuel en cm

omega = V0_CM_S / max(rayon_cm, 1e-6) # Omega = Vt / r

vt = omega * rayon_cm # Vitesse tangentielle réelle

theta = (theta + omega * dt) % (2 * math.pi) # Rotation du disque

update_trace(r_px) # Mise à jour de la trace

rayon_data.append(rayon_cm) # Ajout du rayon dans la courbe

omega_data.append(omega) # Ajout de omega

vt_data.append(vt) # Ajout de Vt

if len(rayon_data) > MAX_POINTS:

rayon_data.pop(0)

omega_data.pop(0)

vt_data.pop(0)

else:

rayon_cm = px_to_cm(r_px)

omega = V0_CM_S / max(rayon_cm, 1e-6)

draw_background() # Dessin du fond

screen.blit(heat_surf, (0, 0)) # Affichage heatmap

screen.blit(trace_surf, (0, 0)) # Affichage trace

draw_disk(theta) # Dessin disque

draw_pion(r_px) # Dessin pion

draw_hud(r_px, omega, Nbp) # Affichage informations

draw_speed_bar(omega) # Barre vitesse angulaire

draw_graph() # Courbes

if paused:

pause_text = FONT_BIG.render("PAUSE", True, YELLOW)

screen.blit(pause_text, (WIDTH // 2 - 60, HEIGHT - 80))

pygame.display.flip() # Rafraîchissement écran

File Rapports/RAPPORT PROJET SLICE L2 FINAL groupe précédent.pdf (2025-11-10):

# PROJET TUTEURÉ: SLICE

SLIDIND CONTACT INVESTIGATION FOR CARBON PANTOGRAPH WEAR EVALUATION

26 MAI 2025
UFR STGI
ESTEBAN CONSTANTIN
BOBA MBARECK
SAMI BOUAYADI
YANIS DJERROUD

## REMERCIEMENTS

Nous tenons à exprimer notre sincère gratitude à nos encadrants de projet, messieurs Philippe Baucour ainsi que Cyrille Verna, pour leur accompagnement constant, leur disponibilité et leurs conseils éclairés tout au long de l’année. Leur soutien a été déterminant dans la compréhension et la mise en oeuvre de notre projet.

Nous remercions également Monsieur Roger Bédu, enseingnant en électronique et automatique, pour son aide précieuse concernant les aspects électroniques du projet.

Nos remerciements s’adressent également à Monsieur Oreen OUMER, doctorant au laboratoire FEMTO-ST, pour nous avoir permis de maniopuler le banc expérimental et pour avoir pris le temps de répondre à nos nombreuses interrogations avec clarté et bienveillance.

Enfin, bien que n’ayons pas eu l’occasion de le rencontrer, nous souhaitons remercier Monsieur Théo KZYAZIK pour la richesse et la pertinence de sa thèse, qui a constitué une ressource essentielle à l’élaboration de notre travail.

### TABLE DES MATIERES

Introduction générale | p. 4
I. Contexte et fonctionnement de la liaison caténaire-pantographe ........ p. 7
1.1. Introduction au fonctionnement de la liaison électrique | p. 7
1.2. Modélisation de la liaison électrique au FEMTO-ST | p. 9
1.3. Intérêt de ce banc expérimental pour le projet SLICE ........ p. 10
II. Objectifs et encadrement du projet SLICE | p. 11
2.1. Objectifs du projet SLICE | p.11
2.2. Adaptation du banc expérimental au projet et défis
| rencontrés..... p. 11
2.3. Début des travaux du semestre de printemps | p. 13
2.4. Travaux à réaliser pendant les congés | p. 14
2.5. Conception mécanique de la maquette et résultats obtenus.... p.15
III. Analyse, évaluation de la maquette | p. 18
3.1. Comparaison des résultats théoriques et expérimentaux | p.
| 18
3.2. Bilan concernant ces résultats | p. 19
IV. Conclusion | p.20
V. Références bibliographiques | p. 22
VI. Annexes | p. 24
6.1. Programmes Arduino | p. 24
6.2. Liste du matériel à commander | p. 25
6.3. Dessins de la pièce supportant le pion | p.26

### TABLE DE FIGURES

Figure 1.1 – Camions à pantographe sur une voie d’autoroute équipée d’une caténaire
| p. 7
Figure 1.2 – Schéma de la liaison caténaire-pantographe | p. 8
Figure 1.3 – Banc expérimental au FEMTO-ST ainsi que ses diRérentes composantes
| p. 9
Figure 1.4 – Maquette finalisée avec moteurs pour disque et pion |
p. 18
Figure 1.5 – Zones parcourues par le pion (ici un crayon) sur le disque
| p. 20

### INTRODUCTION

Depuis quelques années, le laboratoire FEMTO-ST dispose d’un banc expérimental simulant le contact électrique glissant que l’on retrouve pour l’alimentation des trains. Un train utilise un pantographe formé d’une bande en carbone qui va frotter sur le fil d’alimentation du train appelé caténaire. Le projet SLICE (Sliding Contact Investigation for Carbone pantograph wear Evaluation) a pour but d’étudier les phénomènes d’usure de ce contact dynamique réalisé via une bande en carbone au contact du fil de caténaire lors du passage du courant. Ainsi, ce projet vise à modéliser et reproduire ce contact à travers un banc expérimental afin de mieux comprendre les mécanismes d’usure et d’échau^ement.

De ce fait, le premier objectif de notre groupe était de bien comprendre le banc expérimental présent au laboratoire FEMTO-ST. Ce dernier est composé d’un disque en cuivre en rotation sur lequel vient frotter un pion en carbone qui e^ectue des allers-retours selon un rayon. Il y a donc une modélisation de la cinématique à mettre en place afin que la vitesse relative du pion par rapport au disque reste constante. L’ensemble disque/pion est parcouru par un courant analogue à celui que l’on peut retrouver pour l’alimentation des trains.

Ainsi, l’objectif du projet est double :
- La réalisation d’une maquette pédagogique qui reproduit le fonctionnement du banc expérimental. Les mouvements du disque et du pion doivent être reproduits. Une solution asservissant la position du pion à la vitesse de rotation peut même être envisagée. Il n’est pas forcément nécessaire de reproduire le contact électrique.
- L’écriture d’un code Python qui permet de visualiser les zones visitées par le pion du disque et de réaliser une animation du mouvement. En e^et, le pion frottant sur le disque, la connaissance de la position de la surface de contact est importante pour interprétation des résultats. D’un point de vue logiciel, on utilisera la bibliothèque Pymunk qui est, une bibliothèque Python pour la simulation de la physique 2D, particulièrement utile pour les aspects mécaniques et cinématiques.

Au cours du semestre 3, notre principal objectif a été de bien comprendre les attentes liées au sujet du projet. Pour cela, nous avons consacré plusieurs séances à des recherches bibliographiques approfondies, essentielles pour appréhender le fonctionnement de la liaison caténaire-pantographe dans les systèmes ferroviaires. Ces lectures, appuyées par des schémas explicatifs, nous ont permis d’acquérir les premières notions nécessaires à l’analyse du problème, notamment en matière de calcul de vitesse relative et de système d’asservissement.

Sur cette base, nous avons commencé à esquisser une première idée de maquette pédagogique. Celle-ci reposait sur un système de bielle-manivelle, couplé à un disque en rotation, où une craie – tenue par la bielle - se déplacerait selon un rayon de disque pour simuler le mouvement du pion. Toutefois, nous avons rapidement identifié une di^iculté : la vitesse de rotation du disque n’étant pas constante, il devenait nécessaire de synchroniser les deux moteurs par un système d’asservissement afin de maintenir une vitesse relative constante entre les deux éléments. N’ayant pas les compétences techniques su^isantes dans ce domaine, nous avons sollicité l’aide de Monsieur Bedu, notre enseignant en électronique et automatique, pour mieux comprendre les possibilités d’asservissement adaptées à notre projet.

Durant le semestre 4, les échanges réguliers avec nos encadrants et une seconde visite au laboratoire FEMTO-ST, durant laquelle nous avons pu observer le banc expérimental en fonctionnement, nous ont permis de clarifier notre approche. Nous avons ainsi réévalué certaines des pistes envisagées au semestre précédent, et abandonné certaines solutions trop complexes ou irréalisables dans le temps imprévu.

Nous avons alors opté pour une nouvelle orientation : reproduire le banc expérimental du laboratoire à une échelle réduite, en l’adaptant aux contraintes matérielles et temporelles de notre projet. Ce choix nous a permis de recentrer notre travail sur l’aspect électronique de la maquette, en concevant un système fonctionnel tout en restant fidèle au principe du dispositif réel.

En revanche, par manque de temps et à cause d’une organisation rendue di^cile au semestre 3, nous n’avons pas pu développer le code Python prévu pour visualiser les zones parcourues par le pion sur le disque. Nénamoins, nous avons trouvé une alternative simple mais e^icace : utiliser un feutre en translation pour matérialiser le passage du pion, permettant ainsi de visualiser concrètement les zones de contact entre le disque et le pion.

Ce rapport est structuré en trois grandes parties :

I. Contexte et fonctionnement de la liaison caténaire-pantographe
Nous présenterons les principes de fonctionnement de cette liaison électrique glissante, essentielle dans l’alimentation des trains, en nous appuyant sur les connaissances tirées de nos recherches bibliographiques et de nos échanges avec nos encadrants.
II. Objectifs et encadrement du projet SLICE
Cette partie rappellera les objectifs pédagogiques et techniques du projet SLICE, ainsi que les attendus liés à la modélisation et à la réalisation d’une maquette inspirée du banc d’essai du laboratoire FEMTO-ST. Nous reviendrons par la suite sur les travaux menés lors des semestres 3 et 4.

III. Analyse, évaluation de la maquette
Nous comparerons les résultats obtenus à la théorie initiale afin d’évaluer la pertinence de la maquette développée.

IV. Conclusion générale
Enfin, nous conclurons sur les apports techniques et méthodologiques de ce projet, ainsi que sur les perspectives d’amélioration.

### Contexte et fonctionnement de la liaison caténaire-pantographe

1.1 ) Introduction au fonctionnement de la liaison éléctrique

La liaison caténaire-pantographe est un système de contact électrique glissant utilisé pour alimenter les trains électriques en courant. Définissons d’abord les termes principaux de cette liaison électrique :

- Caténaire : Structure suspendue composée d’un fil porteur et d’un fil de contact. Ce dernier est généralement en cuivre pour ses bonnes propriétés conductrices.
- Pantographe : Bras articulé sur le toit du train, maintenant une pression constante sur la caténaire. Il est surmonté de bandes de captages qui assurent le contact glissant.
- Bande de captage : Element en carbone qui frotte sur le fil de contact. Elle est soumise à l’usure et à des échau^ements dus au frottement et au passsage du courant.

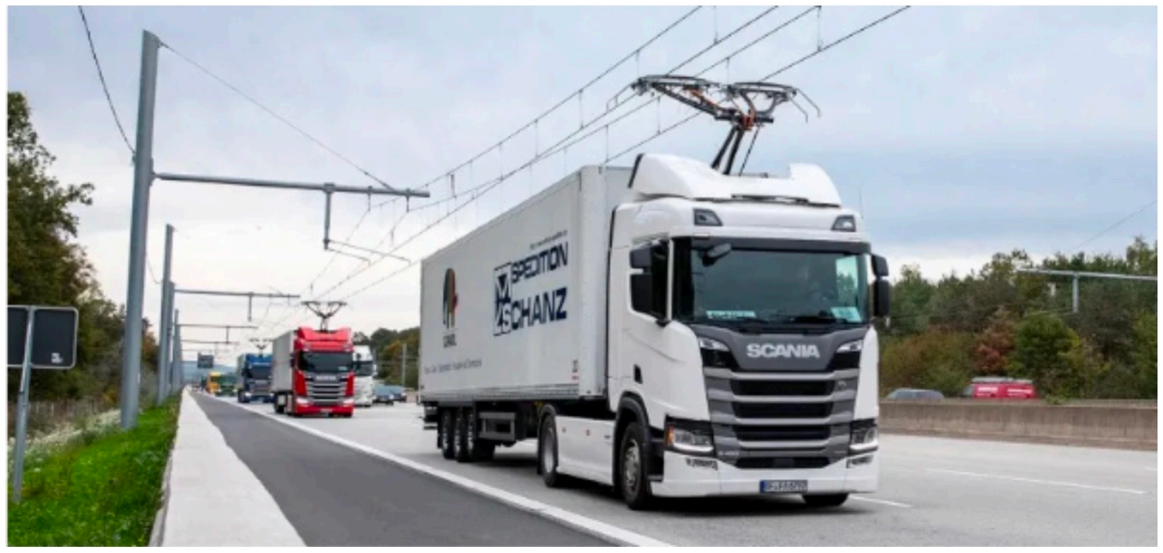
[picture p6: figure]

FIGURE 1.1 – Camions à pantographe sur une voie d’autoroute équipée d’une caténaire.

Ce contact glissant doit étre stable malgré les variations de vitesse ou les courants d’airs induits par le déplacement du train. Ainsi, le mouvement relatif entre le pantographe et la caténaire engendrent des phénomènes d’usure des matériaux : frottement mécanique, dégradation de la surface ou encore la formation d’arcs électriques. L’usure dépend fortement de la vitesse de glissement, la force de contact, le courant et les arcs électriques générés par celui-ci ou encore le type de graphite utilisé. Typiquement, la bande de captage est réalisée en carbone due à sa résistance thermique et ses propriétés auto-lubrifiantes. Néanmoins, elle nécessite une maintenance régulière due à son usure et se retrouve à être coûteuse.

Le pantographe, situé sur le toit du train, exerce une pression pour rester en contact avec la caténaire malgré les irrégularités de la voie. Pendant le roulement, le pantographe glisse sur la caténaire et, si rien n’est fait pour l’uniformiser, ce glissement provoque une usure localisée de la bande de captage en carbone présente sur le pantographe. De ce fait, pour répartir cette usure de manière homogène sur la largeur de la bande de captage, la caténaire est légèrement désaxée en zigzag, oscillant latéralement. Ce mouvement latéral assure ainsi un frottement entre la bande de carbone et le fil de cuivre délocalisé, limitant donc l’usure d’une seule zone, prologeant la durée de vie de la bande de captage et permettant à cette liaison électrique de s’avérer moins coûteuser car moins de maintenace à e^ectuer.

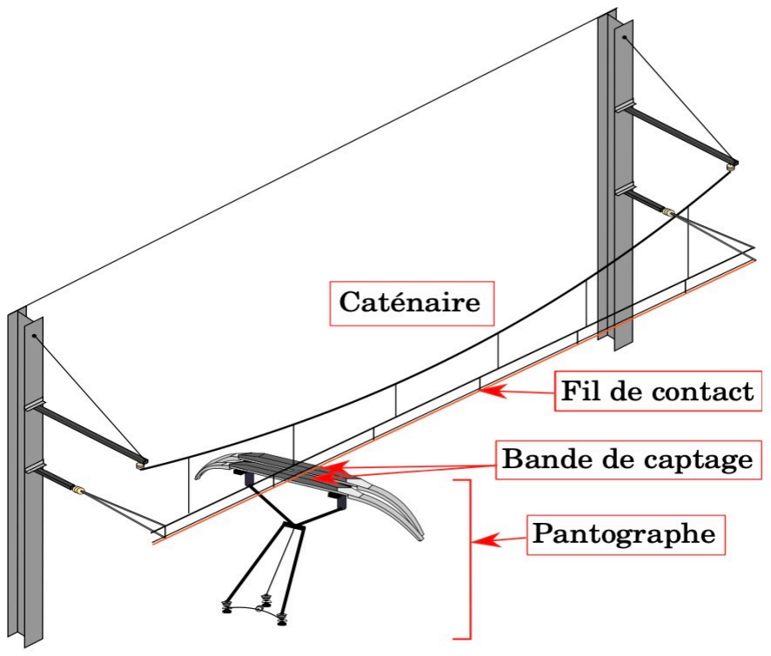
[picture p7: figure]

FIGURE 1.2 – Schéma de la liaison caténaire-pantographe.

Au delà du problème de l’usure, le passage du courant électrique à travers le contact crée une résistance électrique, source d’échau^ement. Ainsi, en cas de mauvais contact, la température peut très rapidement monter, causant une déformation et une détérioration des matériaux et donc une augmentation de l’usure. Le désaxage de la caténaire en zigzag permet une meilleure répartition de la chaleur générée par la liaison sur une surface plus large.
1.2 ) Modélisation de la liaison électrique au FEMTO-ST

Afin d’étudier cette liaison dans un cadre contrôlé, un banc d’essai expérimental a été développé au laboratoire FEMTO-ST, composé de :
- Un disque de cuivre représentant la caténaire
- Un pion en carbonequi simule la bande de captage sur le pantographe

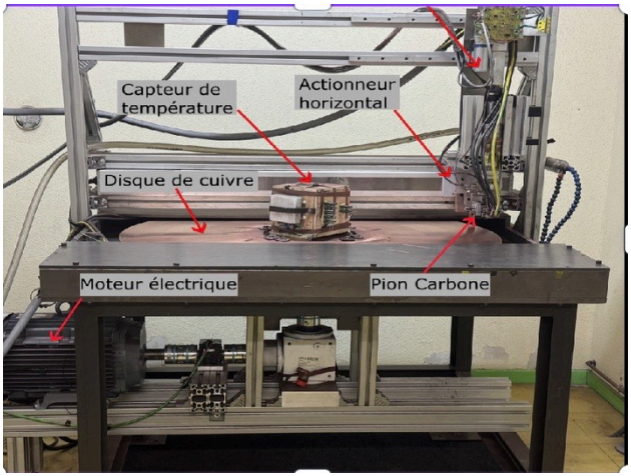
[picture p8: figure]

FIGURE 1.3 – Banc expérimental au FEMTO-ST ainisi que ses di^érentes composantes. Image extraite de la vidéo explicative de la liaison caténaire-pantographe.
L’ensemble est alimenté par un courant électrique.

Le pion e^ecute des mouvements de va-et-vient sur le rayon du disque, pendant que celui-ci tourne, en laissant un battement au centre et à l’extremité. De ce fait, nous remarquons que plus le pion se rapproche du centre du disque, plus la vitesse de rotation de ce dernier augmente. Cela est rendu possible avec un asservissement entre le moteur du disque ainsi que le moteur du pion. En e^et, le fait de récupérer la position du pion sur le disque, notamment grâce à des capteurs de positions, permet d’asservir les deux moteurs. Cela permet donc de conserver une vitesse relative constante afin de reproduire le plus fidèlement la physique du contact réel présent dans les systèmes ferroviaires. En plus de cela, cela nous permet d’obtenir un frottement mécanique constant et donc de d’étudier plus simplement l’usure des matériaux. Nous pouvons également remarquer l’usure du pion en carbone, qui vient marquer le disque de cuivre au fur et à mesure qu’il avance. La manipulation s’avère asssez impressionante étant donné que la vitesse de rotation du disque de cuivre peut aller jusqu’à 80km/h .

1.3 ) Intérêt de ce banc expérimental pour le projet SLICE

Le fait de voir la manipulation au FEMTO-ST nous a permis de nous rendre compte des éléments essentiels à conserver dans notre projet d’année, soient l’explication de cette liaison électrique à travers une maquette pédagogique, davantage accès grand public, ainsi qu’une conservation d’une vitesse relative constante afin de pouvoir être le plus fidèle possible au banc d’essai, et donc à fortuiri à la réalité.

### Objectifs et encadrement du projet SLICE

2.1) Objectifs du projet SLICE

Après avoir étudié en détail le fonctionnement de la liaison caténaire-pantographe, nous disposons désormais d’une compréhension plus précise des attendus de notre projet pour l’année. L’objectif étant de concevoir une maquette pédagogique illustrant cette liaison électrique propre aux systèmes ferroviaires, il est apparu essentiel de nous inspirer du banc d’essai développé au laboratoire FEMTO-ST.

Notre maquette devra donc reproduire de manière simplifiée les mouvements relatifs entre le pion en carbon eet le disque en cuivre. Un point fondamental à respecter est la conservation d’une vitesse relative constante entre ces deux éléments.. Afin de garantir cette constance, une solution technique consiste à asservir les moteurs : l’un entraînant la rotation du disque, l’autre assurant la translation du pion.

En complément de cet aspect mécanique, nous envisageons également de modéliser les zones parcouries par le pioon sur le disque grâce à un code Python. Ce programme s’appuiera sur la bibliopthèque Pymink, dédiée à la simulation de la physique 2D, notamment en mécanique et en cinématique.
2.2) Adaptation du banc expérimental au projet et défis rencontrés

Dès la découverte du sujet, nous avons entamé une phase de réflexion sur le design de la maquette. Conformément aux recommendations, notre idée a été de reproduire les principes du banc expérimental, tout en l’adaptant aux contraintes imposées, notamment le budget que 500 euros que nous nous étions fixés ainsi que les dimensions réduites d’un modèle pédagogique. Nous avons imaginé une maquette composée ;
- D’un disque de 12cm de rayon,
- Et d’un pion en translation sur 8cm du rayon, laisssant un battement de 2cm au centre et à l’extrémité du disque.
Le mouvement du pion serait assuré par un premier moteur avec une vitesse de translation de 2km/h, tandis que la rotation du disque serait confiée à un second moteur.

Pour garantir une vitesse relative constante, il nous fallait déterminer une vitesse de rotation du disque en fonction de la position du pion. En nous appuyant sur la thèse de Monsieur Théo KZYAZIK, nous avons utilisé la formule suivante pour calculer la vitesse théorique de rotation :
Vrot= (Vt×10E6)/(60×2πR)
Où:
- Vt est la vitesse de rotation (en mm/min)
- R est le rayon parcouru par le pion (en mm) Ainsi, nous obtenons les résultats suivants :
- A l’extrémité du disque (80mm) :

Vrot,ext= (2.1E6)/(60.2. π.80)= 66,31 tr/min

- Près du centre du disque (20mm) :

Vrot,int=(2.1E6)/(60.2. π.20)=265,258 tr/min

Ces résultats mettent en évidence un poin crucial : plus le pion s’approche du centre de disque, plus la vitesse de rotation de celui-ci doit augmenter pour conserver une vitesse tangentielle constante. Cela signifie que sans asservissement des moteurs, la vitesse relative ne resterait pas constante, ce qui fausserait l’interprétation des phénomènes d’usure .
Suite à nos interrogations sur la conservation d’une vitesse relative constante entre le pion et le disque, nous avons sollicité l’avis de Monsieur Bédu, enseignant en électronique et en automatique. Celui-ci nous a conseillés d’intégrer à notre système une boucle de régulation basée sur un microcontrôleur, associé à un encodeur de position. L’objectif de cette solution serait d’ajuster dynamiquement la vitesse de rotation du disque en fonction de la position du pion, garantissant ainsi la constance de la vitesse tangentielle. L’utilisation d’une carte Arduino, combinée à ces composants, permettrait également de corrriger automatiquement les écarts de vitesse observés, en mettant en oeuvre un asservissement en temps réel.

Une fois cette approche clarifiée, notre attention s’est portée sur la problématique du déplacement linéaire du pion. Après plusieurs échanges au sein du groupe, nous avons envisagé un système mécanique de bielle-manivelle, capable de générer un mouvement de translation régulier. Afin d’assurer, un guidage rectiligne précis, nous avons également imaginé la mise en place de rails fixes positionnés sur le disque, qui contraindraient la trajectoire du pion dans une direction rectiligne.

Ce semestre d’automne s’est ainsi conclu par l’élaboration de premières esquisses de conception de la maquette, alliant réflexion mécanique et début de réfléxion sur l’aspect électronique. Toutefois, il est vite apparu que notre principal défi résiderait dans la mise en oeuvre de l’asservissement des moteurs. Aucun membre du groupe n’ayant encore expérimenté le pilotage de moteurs avec un microcontrôleur ni travaillé avec des kits Arduino, ce point a soulevé des incertitudes quant à notre capacité à concrétiser cette partie du projet à court terme. Cela a eu pour conséquence un retard dans notre avancement global, a fortuiri sur notre avancement du second semestre.

2.3) Début des travaux du semestre de printemps

Le semestre de printemps a débuté par une seconde visite au laboratoire FEMTO-ST, au cours de laquelle nous avons pu observer le banc d’essai en fonctionnement, sous la supervision de notre encadrant Monsieur Philippe BAUCOUR et du doctorant Oreen OUMER. Cette démonstration s’est révélée particulièrement riche d’enseignements : elle nous a permis de mieux prendre conscience de la complexité technique du dispositif réel, et de mesurer le travail considérable nécessaire à sa conception et sa mise en oeuvre.

Cette visite a également été l’occasion d’un échange approfondi avec Monsieur Baucour au sujet de nos dernières avancées et des idées que nous avions en tête pour la conception de notre maquette. Etant donné les contraintes organisationnelles et le fait que nous étions déjà à la mi-février, il nous a été recommandés de simplifier notre conception en repartant directement du principe même du banc d’essai FEMTO-ST, et en abandonnant le système bielle-manivelle initialement envisagé pour la translation du pion, jugé trop imprécis pour notre objectif.

A la place, il a été proposé de recourir à un système à courroie, plus fiable et plus simple simple à mettre en oeuvre, où le pion serait maintenu par une pièce concue en impression 3D.

Afin de concrétiser cette nouvelle orientation, nous avons organisé plusieurs réunions avec notre second encadrant, Monsieur Verna, enseignant en mécanique. Ces échanges nous ont permis de mieux cadrer la conception mécanique de la maquette. Après avoir établi une liste des composants nécessaires, nous l’avons transmises à nos encadrants. Il s’est avéré que Monsieur Verna disposait déjà d’une partie du matériel demandé, ce qui nous a permis d’éviter certaines commandes.

Cependant, dans un souci de simplification et afin d’éviter de surcharger la maquette, Monsieur Verna nous a proposés une alternative plus e^icace : utiliser des moteurs pas à pas, déjà disponibles dans les salles de TP. Ces moteurs présentent l’avantage de permettre un contrôle précis de la position du pion sans nécessiter de capteurs de positions externes, cette dernière étant connue en fonction du nombre de pas e^ectués.
2.4) Travaux à réaliser pendant les congés

A l’approche des congés de Pâques, nous avons tenu une dernière réunion avec nos encadrants pour faire le point sur les tâches à réaliser pendant cette période. Plusieurs objectifs nous ont été confiés :
- Etablir une liste détaille des dernières pièces à commander sur le site du fournisseur RadioSpares pour compléter la maquette.
- Réaliser un protoype de programme Arduino permettant de faire varier la vitesse du moteur pas à pas, notamment celui destiné à entraîner le disque. De code devrait être conçu en langage Arduino et devrait permettre de contrôler la vitesse via des signaux numériques, c’est-à-dire en fonction du nombre de 0 et 1 renvoyés en sortie.
N’ayant jamais programmé de carte Arduino auparavant, nous avons été orientés vers des ressources en ligne, telles que le site Clockwise, pour apprendre à :
- Faire tourner les moteurs pas à pas ( disque et pion) à des vitesses données.
- Faire varier le sens de rotation et simuler des phases de décélération.
- Ajouter à la carte Arduino une extension, un shield, pour augmenter le nombre de ports de sortie disponibles et permettre la connexion simultannée de plusieurs composants, ici plusieurs moteurs.

A notre retour des vacances de Pâques, nous avons découvert la structure de la maquette, réalisée en grande partie par notre encadrant Monsieur Verna. Cette reprise a également été l’occasion de lui présenter notre travail personnel e^ectué durant les congés, notamment les premiers essais de programmation sur carte Arduino.

Nous avons ainsi pu tester nos codes directement sur la carte, et vérifier le bon fonctionnement du moteur pas à pas que nous avait prêtés Monsieur Verna. Deux programmes ont été élaborés, que vous retrouverez en annexe.

Ces essais nous ont permis de valider la communication entre la carte Arduino et les moteurs. Une comparaison entre les résultats théoriques et expérimentaux sera proposée plus loin dans le rapport.

Une fois les dimensions du disque ajustée à la structure existante (6,15cm de rayon parcourus par le pion, 1,35cm de battement à l’intérieur et 3cm de battement à l’extérieur soit 10,5cm de rayon), nous avons procédé à la commande des éléments restants nécessaires à l’assemblage final de la maquette. Cela comprenait :
- Les composantes électroniques complémentaires,
- Un revêtement en ardoise à poser sur le disque,
- Ainsi que des feutres pour ardoise servant de pions traceurs simulant le contact avec la caténaire.
La liste complète des composants commandés ainsi que les programmes Arduino figurent en annexe du présent rapport.
2.5) Conception mécanique de la maquette et résultats obtenus

En parallèle, nous avons entrepris la conception d’une pièce. En impression 3D destinée à supporter le feutre-pion sur le disque. A cette fin, nous avons réalisé des schémas annotés, permettant de définir précisément les dimensions et la géométrie de la pièce. Celle-ci a ensuite été fabriquée par Monsieur Verna à l’aide d’une imprimante 3D. Le schéma de cette pièce légendée sera également disponible en annexe de ce présent rapport.

Une fois les moteurs pas à pas réceptionnés, nous avons pu les fixer sur la maquette avec l’aide de Monsieur Verna. Le moteur dédié à la rotation du disque a été relié à son support via un système de courroie, assurant une transmission mécanique stable et conforme au fonctionnement prévu.

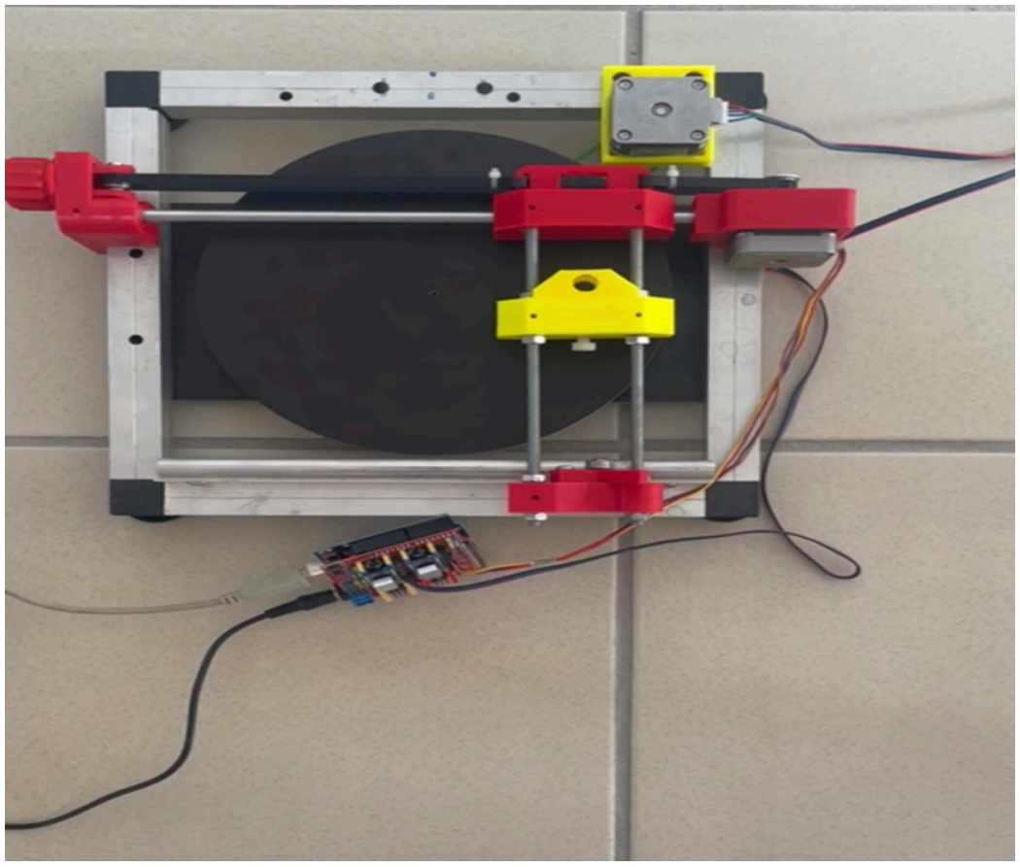
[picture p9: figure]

FIGURE 1.4 - Maquette finalisée avec moteurs pour disque et pion.

Afin de disposer d’un nombre su^isant de ports de sortie pour connecter l’ensemble des composants électroniques de notre maquette, nous avons ajouté à la carte Arduino une extension, un shield. Cet accessoire permet d’augmenter la capacité d’interfaçage tout en conservant une architecte simple.

A notre retour des vacances de printemps, il ne nous restait plus que trois semaines environ pour finaliser une version présentable de la maquette en vue du Festival scientifique INOUIH, où nous devions introduire les travaux du laboratoire du FEMTO-ST. Face à cette contrainte de temps, et après discussion avec Monsieur Baucour, nous avons décidé de renoncer à la conception du code Python,destiné à visualiser les zones parcourues par le pion sur le disque.

En remplacement de cette visualisation numérique, nous avons mis en place une solution matérielle simple : un revêtement en ardoise posé sur le disque, permettant au pion (un feutre) de laisser une trace visible de son passage. Cette alternative répondait à l’objectif pédagogique de montrer concrètement le trajet du pion.

Lors du deuxième jour du Festival INOUIH, le samedi 24 mai 2025, le revêtement en ardoise et les feutres n’étaient pas encore arrivés. Nous avons donc improvisé en utilisant une feuille blanche et du crayon, permettant tout de même de démontrer au public le fonctionnement de notre maquette, en particulier les zones réellemeent visitées par le pion.

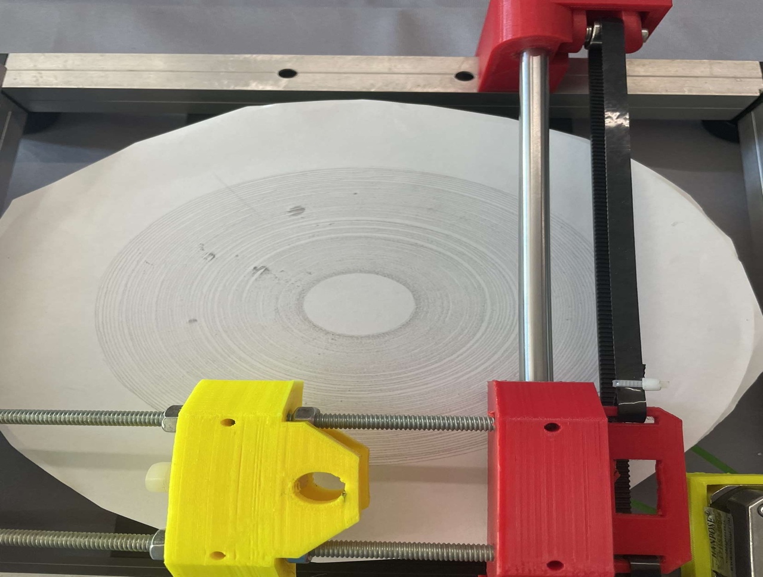
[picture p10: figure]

FIGURE 1.5 – Zones parcourues par le pion- ici un crayon – sur le disque.

### Analyse, évaluation de la maquette

3.1) Comparaison des résulats théoriques et expérimentaux

Avec les nouvelles dimensions du disque de notre maquette, nous avons pu recalculer les vitesses de rotation théoriques en fonction de la position radiale du pion, en nous appuyant sur la relation extraite des travaux de Monsieur Théo KZYAZIK :
Vrot= (Vt×10E6)/(60×2πR)
où:
- Vt est la vitesse de rotation (en mm/min)
- R est le rayon parcouru par le pion (en mm)
En supposant une vitesse de translation constante de 0.5tr/min, nous obtenons les vitesses théoriques suivantes :
- A l’extrémité du disque (75mm) :

Vrot,ext= (0,5E6) / (60.2. π.75)= 17,7 tr/min

- Près du centre du disque (13 ,5mm) :

Vrot,int=(0,5E6) / (60.2. π.13,5)=98,24 tr/min

En comparaison avec les résultats obtenus lors du semestre d’automne, on observe une baisse significative des vitesses de rotation. Cette diminution s’explique principalement par une vitesse de translation du pion plus faible : 0.5 tr/min actuellement contre 2km/h précédemment. Cette adaptation a été rendue nécessaire pour respecter les nouvelles dimensions e la maquette et assurer la stabilité du mouvement.

Lors de la mise en marche de notre maquette, nous avons mesuré les vitesses de rotationsréelles :
- Vitesse pratique à l’extrémité du disque : 21.4 tr/min
- Vitesse pratique près du centre du disque : 95.5 tr/min

Nous avons ensuite déterminé l’incertitude relative entre les valeurs théoriques et les mesures pratiques :

- A l’extrémité du disque (75mm) :

(21.4-17.7) / 21.4 = 20.9%

Près du centre du disque (13 ,5mm) :

(98.24-95.5) / 98.24 = 2.7%
3.2) Bilan concernant ces résultats

Ces résultats montrent que l’écart relatif est plus important à l’extrémité du disque, ce qui s’expliquer par une légère instabilité mécanique et le tangage du disque observé pendant le fonctionnement. Malgré cela, le comportement global de la maquette reste satisfaisant, et elle s’avère suffisamment fiable et pédagogique pour illustrer le principe de la liaison caténaire-pantographe auprès d’un public non spécialiste, notamment dans le cadre du Festival INOUIH.

### Conclusion générale

Le projet SLICE nous a o^erts l’opportunité de nous confronter à une problématique concrète : la modélisation de la liaison caténaire-pantographe, essentielle dans le domaine ferroviaire. A travers l’étude du contact électrique glissant entre un pion en carbone et un fil conducteur, nous avons pu explorer les enjeux mécaniques et électroniques liés à ce système complexe.

Notre démarcher s’est organisée autour de plusieurs axes :
- Une phase de compréhension théorique et de recherches documentaires.
- La modélisation cinématique du mouvement relatif
- La conception d’une maquette pédagogique, fidèle au banc d’essai du laboratoire FEMTO-ST

Le semestre d’automne a été consacré à l’exploration du sujet, aux premières idées de conception, et à l’identification des principales contraintes, notamment liées à l’asservissement des moteurs. Cette période a été marquée par une certaine déstabilisation : nous ne savions pas vraiment comment nous organiser, ni par où commencer. Néanmoins, ce flou a, au fur et à mesure, laissé place à un travail plus structuré, porté par nos encadrants et nos propres e^orts.

Le semestre de printemps a permis une avancée plus concrète, avec une conception plus aboutie, des choix techniques plus simples mais plus e^icaces, et surtout une réalisation complète de la maquette, présentée lors du Festival INOUIH. Nous avons alors ressenti une véritable fierté à exposer le fruit de notre travail à un public, avec une maquette fonctionnelle, démonstrative et fidèle à l’objectif pédagogique initial.

Ce projet a été particulièrement intéressant car il nous a permis de mettre en pratique nos connaissances, souvent abordées de manière théorique en cours. A travers cette démarche, nous avons eu pour la première fois le sentiment de “ faire de l’ingénierie” : concevoir, tester, corriger, améliorer etc. Toutefois, cette phase de concrétisation a aussi mis en évidence nos di^icultés à articuler nos savoirs mécaniques de manière opérationnelle. L’application pratique de la mécanique s’est révélée plus laborieuse que prévu, et constitue un axe d’amélioration évident, en plus de l’organisation, pour la suite

de notre formation.

En définitive, le projet SLICE nous a apportés bien plus que des compétences techniques : il nous a permis de développer notre autonomie, notre esprit de collaboration, notre capacité d’adaptation, mais aussi notre sens de l’analyse critique. Ce fut une expérience exigeante, mais formative, motivante et valorisante, qui restera un moment marquant de notre parcours en deuxième année.

### REFERENCES BIBLIOGRAPHIQUES

- Introduction au sujet, définition des termes clés ( pantographe/ caténaire)

Kziazyk T. Etude expérimentale de l’usure et de l’échauffement d’un contact glissant : application caténaire-pantographe [ Thèse de doctorat en ligne]. Belfort : Université de Bourgogne Franche-Comté ; 2023 [ cité le 11 janvier 2025]. Disponible sur : https://theses.fr/2023UBFCCD043 .

- Fonctionnement général du système ferroviaire

Janssoone D. Technologie fonctionnelle du transport ferroviaire et urbain : train, métro, tramway, RER. Malakoff. Dunod ; 2021.

- Une liaison avec des enjeux industriels importants ( thermiques, mécaniques et chimiques)

Jonckheere B. Caractérisation multi-physique d’une interface multi-contacts à l’arrêt et en mouvement : cas du captage de courant via l’interface caténaire-pantographe [Thèse de doctorat en ligne]. Amiens : Université de Picardie Jules Vernes, 2021 [cité le 11 janvier 2025]. Disponible sur : https/theses.hal-science/tel-03828928v1
- Limites de la liaison pantographe-caténaire et la possibilité de la remplacer

Pereira G, Bartholomeux P, Le Moigne Ph, Rombaut Ch, Van Berten Ph, Poli G. Transport urbain sans caténaire et nouvelles techniques de stockage [En ligne]. 2000 [cité le 11 janvier 2025]. Disponible sur: https://www.osti.gov/etdeweb/servlets/purl/20222891

- Schéma d’une liaison pantographe/caténaire

Louvel P, Ezerzere P, Jourdes P, Robin F, Khimech G. 4. Systèmes embarqués ferroviaires. In : Louvel P, Ezerzere P, Jourdes P, Robin F, Khimech G. Systèmes électroniques embarqués et transports : Automobile, ferroviaire, aéronautique et espace. Malakoff : Dunod ; 2021. p.83-138.

- Intérêt d’une telle liaison d’un point de vue électrique et énergétique

Mange D. Plan rail 2050 : Plaidoyer pour la vitesse [En ligne]. Lausanne : Presses polytechniques et universitaires romandes ; 2010 [ cité le 11 janvier 2025]. Disponible sur : https://univ-scholarvox-com.scd1.univ-fcomte.fr/reader/docid/88838300/page/129?searchterm=pantographe%20caténaire (https://univ-scholarvox-com.scd1.univ-fcomte.fr/reader/docid/88838300/page/129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)

### ANNEXE

6.1) Programmes ARDUINO

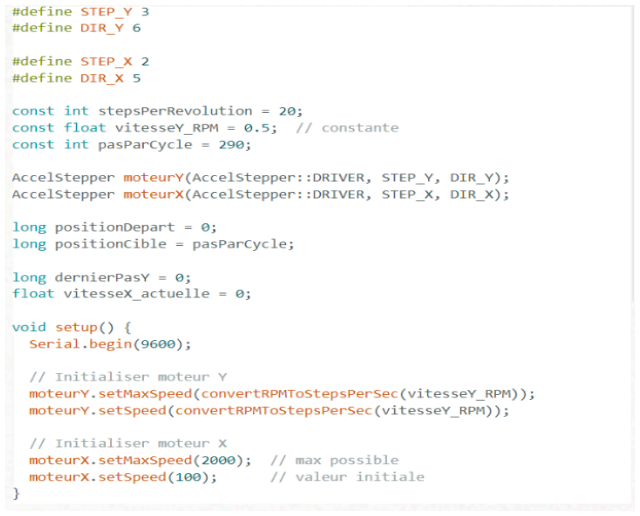
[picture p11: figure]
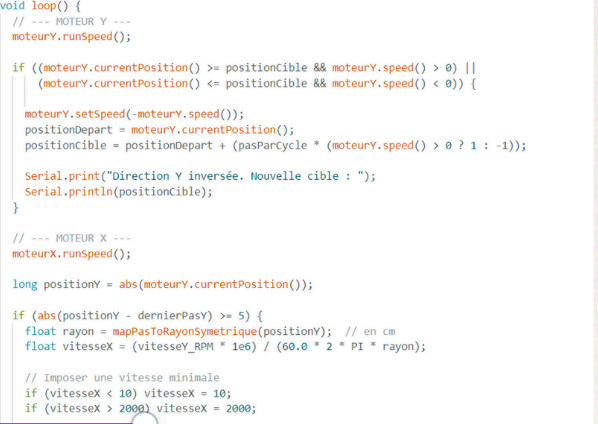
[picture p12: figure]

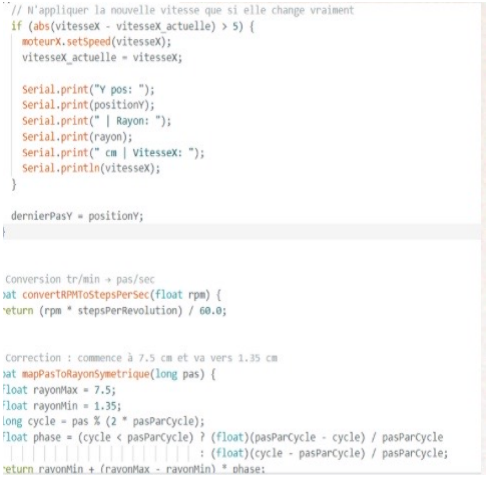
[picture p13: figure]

6.2 ) LISTE DU MATERIEL A COMMANDER :

Désignation | Lien d'achat | Prix (€)
Shield CNC pour Uno ARD-CNC-K1 | Lien (https://www.gotronic.fr/art-shield-cnc-pour-uno-ard-cnc-k1-27753.htm) | 18.8
Carte de développement MikroBUS A9488 | Lien (https://fr.rs-online.com/web/p/modules-de-developpement-pour-la-robotique-la-gestion-d-alimentation-et-les-moteurs/1360748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) | 24.92
2 moteurs (disque et pion) pas à pas de balayage radial NEMA 17 | Lien (https://fr.rs-online.com/web/p/moteurs-pas-a-pas/1805279?gb=s) | 93.64
Support moteur pas à pas NEMA 17 | Lien (https://www.gotronic.fr/art-support-pour-moteur-nema-17-22281.htm) | 5.5
BIC Velleda Rouleau Adhésif Effaçable à Sec 45x50 cm | Lien (https://www.amazon.fr/BIC-Rouleau-Adh%C3%A9sif-Couleurs-Assorties/dp/B001AO18OW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) | 9.96
BIC Velleda Liquid Ink Feutres Premium pour Tableau Blanc Effaçables à Sec Avec Pointe Conique Medium | Lien (https://www.amazon.fr/BIC-Velleda-Pocket-Feutres-Effa%C3%A7ables/dp/B00ARAE4H8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) | 14.94
Courroie synchrone RS PRO 5M Caoutchouc, Long 330mm Largeur 9mm, 66 dents | Lien (https://fr.rs-online.com/web/p/courroies-synchrones/1755201?gb=s) | 5.02
Pack de feutres blancs pour ardoise | Lien (https://www.amazon.fr/Shuttle-Art-effa%C3%A7ables-magn%C3%A9tiques-effacement/dp/B07YXNXV2X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) | 10.79
Colle forte (5 unités) | Lien (https://www.amazon.fr/ARKA-KRAFTPROTZ-Superglue-universelle-caoutchouc/dp/B0BYJGH8SG) | 33.2
Ruban adhésif | Lien (https://www.amazon.fr/Amazon-Basics-r%C3%A9sistance-r%C3%A9parations-bricolage/dp/B07YDQRR51) | 16.46

6.3) Dessins de la pièce supportant le pion

## Pièce vue du dessus :

Les deux barres noires sur le schéma sont les vis, le trou blanc traverse toute la pièce et servira à y mettre le feutre le diamètre du rond blanc sera de

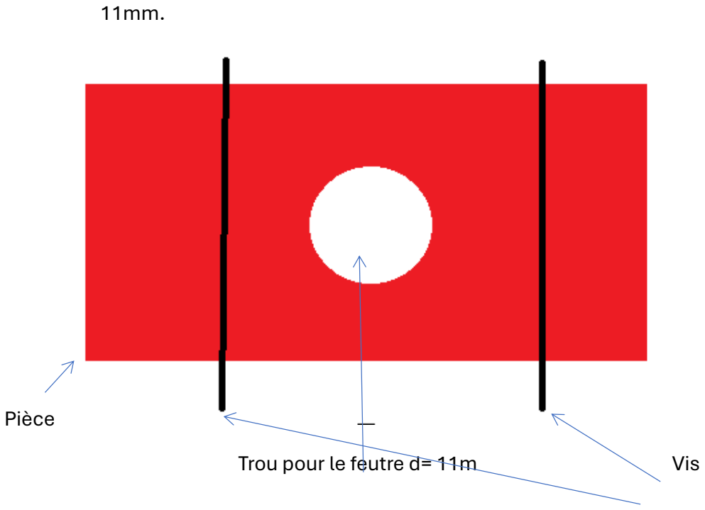
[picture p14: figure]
Pièce; Trou pour le feutre d= 11m; Vis

## Pièce vue du face :

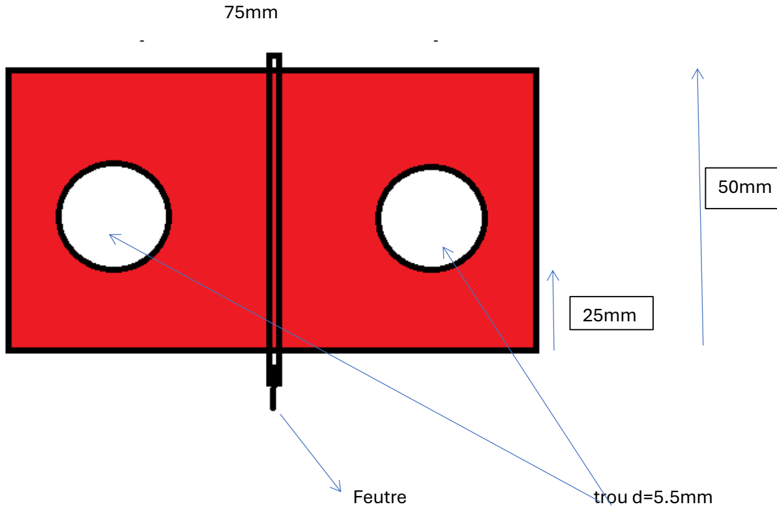
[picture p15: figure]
Feutre; trou d=5.5mm

Les centre des trous des vis de 5.5mm de diamètre sont éloignés du bord de la pièce de 16mm. L’écart entre les deux visses est donc de 38mm.

## Pièce vue de côté :

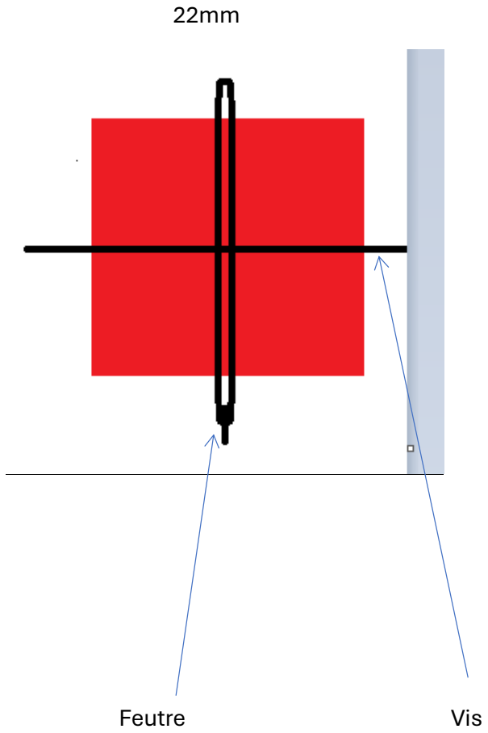
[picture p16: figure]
Feutre; Vis

L’autre option possible est de faire une fente dans le trou du feutre pour y mettre une vis pour faire en sorte de bloquer le feutre.

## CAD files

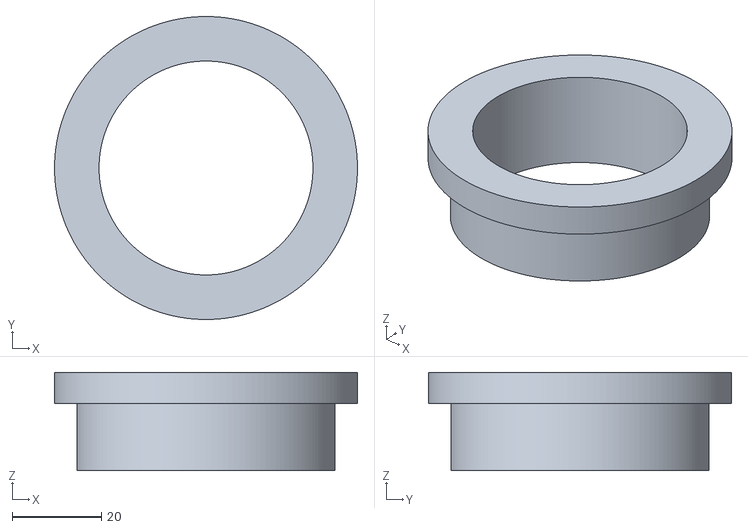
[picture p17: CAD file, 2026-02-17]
Impression 3D/Support Disque.stl
68.0 x 68.0 x 22.0

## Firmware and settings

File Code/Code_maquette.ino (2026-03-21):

#include <AccelStepper.h>

#define STEP_Y 3
#define DIR_Y 6

#define STEP_X 2
#define DIR_X 5

const int stepsPerRevolution = 20;
const float vitesseY_RPM = 0.5;  // constante
const int pasParCycle = 290;

// Constantes de réglage
const long SEUIL_PAS_Y = 5;            // Nb de pas Y avant recalcul
const float VITESSE_X_MIN = 10.0;      // Vitesse min de X
const float VITESSE_X_MAX = 2000.0;    // Vitesse max de X
const float SEUIL_DIFF_VITESSE_X = 5.0;// Variation min pour MAJ moteur X

AccelStepper moteurY(AccelStepper::DRIVER, STEP_Y, DIR_Y);
AccelStepper moteurX(AccelStepper::DRIVER, STEP_X, DIR_X);

long positionDepart = 0;
long positionCible = pasParCycle;

long dernierPasY = 0;
float vitesseX_actuelle = 0;

void setup() {
  Serial.begin(9600);

  // Initialiser moteur Y
  moteurY.setMaxSpeed(convertRPMToStepsPerSec(vitesseY_RPM));
  moteurY.setSpeed(convertRPMToStepsPerSec(vitesseY_RPM));

  // Initialiser moteur X
  moteurX.setMaxSpeed(2000);  // max possible
  moteurX.setMaxSpeed(VITESSE_X_MAX);  // max possible
  moteurX.setSpeed(100);      // valeur initiale
}

void loop() {
  // --- MOTEUR Y ---
  moteurY.runSpeed();

  if ((moteurY.currentPosition() >= positionCible && moteurY.speed() > 0) ||
      (moteurY.currentPosition() <= positionCible && moteurY.speed() < 0)) {

    moteurY.setSpeed(-moteurY.speed());
    positionDepart = moteurY.currentPosition();
    positionCible = positionDepart + (pasParCycle * (moteurY.speed() > 0 ? 1 : -1));

    Serial.print("Direction Y inversée. Nouvelle cible : ");
    Serial.println(positionCible);
  }

  // --- MOTEUR X ---
  moteurX.runSpeed();

  long positionY = abs(moteurY.currentPosition());

  if (abs(positionY - dernierPasY) >= 5) {
  if (abs(positionY - dernierPasY) >= SEUIL_PAS_Y) {
    float rayon = mapPasToRayonSymetrique(positionY);  // en cm
    float vitesseX = (vitesseY_RPM * 1e6) / (60.0 * 2 * PI * rayon);

    // Imposer une vitesse minimale
    if (vitesseX < 10) vitesseX = 10;
    if (vitesseX > 2000) vitesseX = 2000;
    vitesseX = constrain(vitesseX, VITESSE_X_MIN, VITESSE_X_MAX);

    // N'appliquer la nouvelle vitesse que si elle change vraiment
    if (abs(vitesseX - vitesseX_actuelle) > 5) {
    if (abs(vitesseX - vitesseX_actuelle) > SEUIL_DIFF_VITESSE_X) {
      moteurX.setSpeed(vitesseX);
      vitesseX_actuelle = vitesseX;

      Serial.print("Y pos: ");
      Serial.print(positionY);
      Serial.print(" | Rayon: ");
      Serial.print(rayon);
      Serial.print(" cm | VitesseX: ");
      Serial.println(vitesseX);
    }

    dernierPasY = positionY;
  }
}

// Conversion tr/min → pas/sec
float convertRPMToStepsPerSec(float rpm) {
  return (rpm * stepsPerRevolution) / 60.0;
}

// Correction : commence à 7.5 cm et va vers 1.35 cm
float mapPasToRayonSymetrique(long pas) {
  float rayonMax = 7.5;
  float rayonMin = 1.35;
  long cycle = pas % (2 * pasParCycle);
  float phase = (cycle < pasParCycle) ? (float)(pasParCycle - cycle) / pasParCycle
                                      : (float)(cycle - pasParCycle) / pasParCycle;
  return rayonMin + (rayonMax - rayonMin) * phase;
}

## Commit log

2025-11-10 Ajout code arduino maquette
2026-02-05 Réorganisation des fichiers
2026-05-04 Move old sketch and add new maquette code
    Rename old Code_maquette.ino to Code_maquett_ancien.ino and add a refactored Code/Code_maquette/Code_maquette.ino. The new sketch uses AccelStepper, defines step/dir pins and physical constants, impl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
2026-05-05 Improve heatmap alpha and HUD radial velocity
    Increase heatmap alpha sensitivity (alpha now = min(220, 20 + c*5)) to make density more visible. Add v_r_val parameter to draw_hud and compute v_rel using the actual radial speed; pass the runtime v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
2026-05-20 Apply mechanical multiplier to X steps/rev
    Introduce multiplicateur_mecanique (2.83) and use it to calculate stepsPerRevolutionX as 200 * multiplicateur_mecanique to account for the mechanical reduction on the X axis. Note: multiplicateur_mec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
2026-05-20 Adapt stepper code for CNC shield (full-step)
    Add CNC shield enable pin and full-step/microstepping support; introduce MICROSTEPPING constant and use it to compute stepsPerRevolution and pasParCycle. Adjust safety/tuning values (lower SEUIL_PAS_Y, reduced VITESSE_X_MAX and SEUIL_DIFF_VITESSE_X) and constrain speed updates to avoid small fluctuations. Activate shield in setup (EN LOW), add initialization Serial message, and tidy/comment code in French (refactor comments and section headers). Changes aim to make the sketch work reliably with a CNC shield in full-step mode and improve speed control stability.
    [Code_maquette.ino]
2026-05-20 Add Serial debug logs for motor events
    Insert Serial prints in Code_maquette.ino to aid debugging: log the target position on Y-motor inversion ("Inversion Y. Cible : <pos>") and log rayon, X motor speed (vitesseX) and current Y position 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
2026-05-25 Add files via upload
    CR projet pas fini mais avec début de conclusion et codes arduino en annexe
2026-05-25 Reorganize code into Arduino and Python dirs
    Move and reorganize project sources: Arduino .ino sketches moved into Code/Arduino and Python scripts moved into Code/Python (e.g. Banc_expérimental_amélioré.py and Banc_SLICE.py -> Code/Python/Simul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
2026-05-25 Normalize filenames and reorganize assets
    Renamed files to remove spaces/special characters and use underscores for consistency, and moved the 3D model into the proper folder. Affected files: Code/Python/Code python avec Nb pas.py -> Code/Py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
    [Support Disque.stl]
